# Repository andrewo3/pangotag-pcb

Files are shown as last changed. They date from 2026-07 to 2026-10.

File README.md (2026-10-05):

# Pangotag PCB

KiCad 10 project for a GNSS and motion tracking tag for the white-bellied pangolin, built in the
Harvard Microrobotics Laboratory.

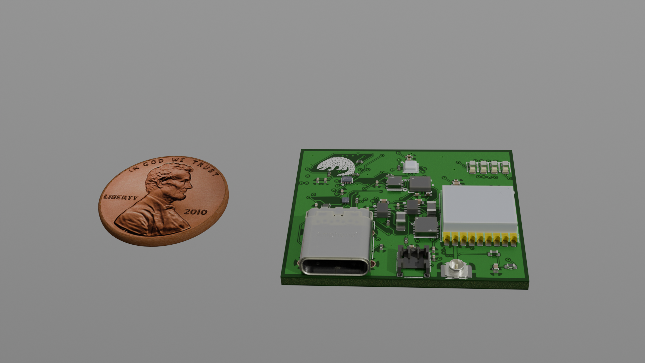
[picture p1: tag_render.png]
The V2 board next to a penny


## V2

`Pangotag_PCB_LCSC_compat4.kicad_pcb` is the V2 tag: a 31.94 × 27.18 mm, 6-layer, 1.6 mm board with
80 parts on both sides, using parts that JLCPCB stocks.

- STM32U575 microcontroller (LQFP-64) and a 32 GB eMMC on the underside
- u-blox MAX-M10S GNSS module with a U.FL antenna connector
- BMI270 IMU, BMP581 pressure sensor, T117 temperature sensor and LTC2944 coulomb counter on one I2C bus
- Two TPS62840 buck converters for always-on 1.9 V and 3.3 V rails, fed from a 2-pin battery connector
- USB-C for USB and, with a Type-C debug accessory, SWD: two comparators on CC1 and CC2 and an AND
  gate switch a TMUX1511 that puts SWCLK, SWDIO, SWO and NRST on contacts USB 2.0 leaves unused

`Dongle.kicad_pcb` is a 4-layer adapter that connects an ST-Link to the tag's USB-C port in either
orientation, with a reset button.

## Files

| Path | Contents |
| --- | --- |
| `Pangotag_PCB.kicad_sch` and its `Power`, `Communication`, `LEDs` and `st-link_conn` sheets | Schematic |
| `Pangotag_PCB_LCSC_compat4.kicad_pcb` | V2 tag board |
| `Dongle.kicad_pcb` | ST-Link debug dongle |
| `Pangotag_PCB.kicad_pcb` | The tag and an earlier dongle on one sheet |
| `Pangotag_PCB_LCSC_compat*.kicad_pcb`, `Only_Tag*.kicad_pcb` | Intermediate revisions |
| `jlcpcb/` | JLCPCB Gerber, BOM and placement files |
| `export_footprints.pretty/`, `FBGA153.pretty/`, `*.kicad_sym` | Project footprint and symbol libraries |
| `tag_render*.png` | Renders of the board and an enclosure model |

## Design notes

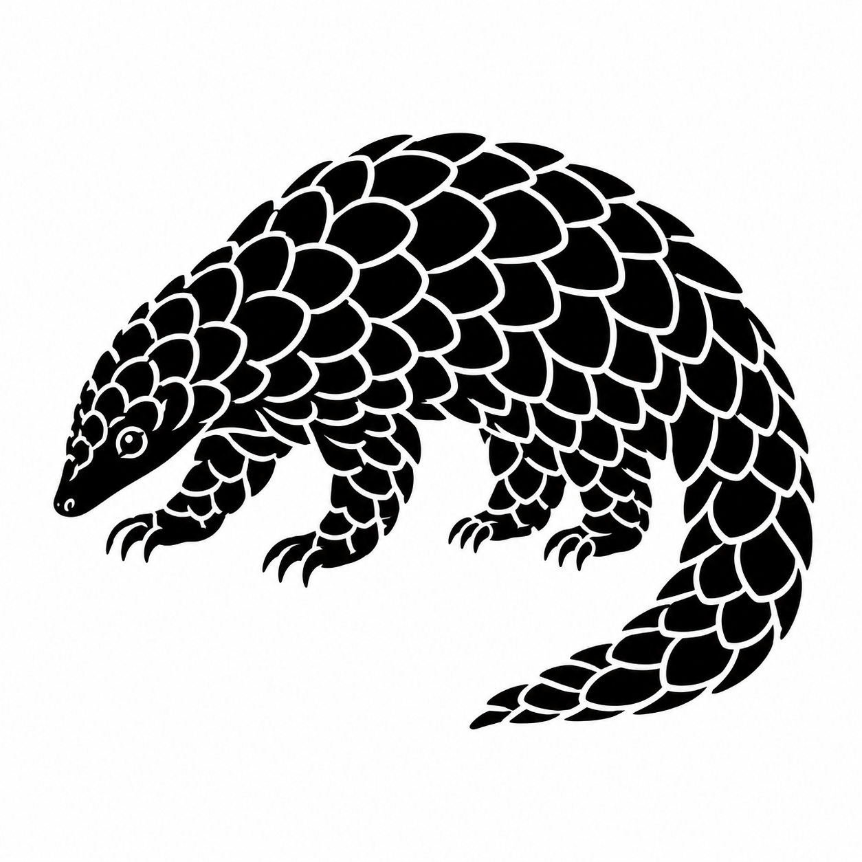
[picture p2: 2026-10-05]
pangolin_decal.png

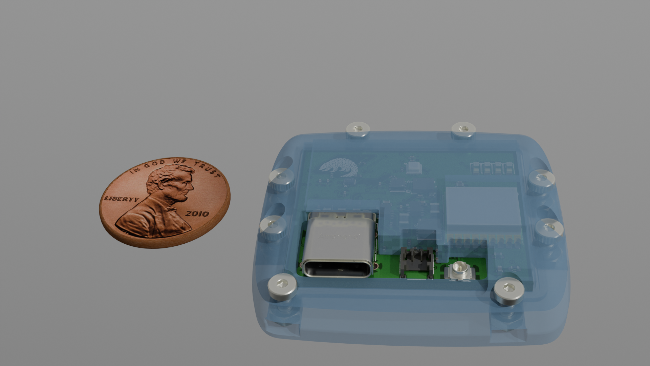
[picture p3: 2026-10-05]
tag_render2.png

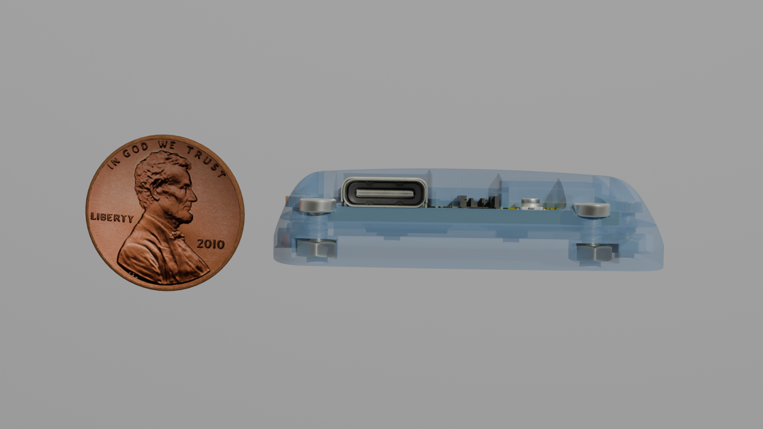
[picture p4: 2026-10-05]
tag_render3.png

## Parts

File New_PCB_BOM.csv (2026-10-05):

Id | Designator | Footprint | Quantity | Designation | Supplier and ref
1 | BT1, BT2, BT3 | BAT_2996 | 3 | 2996
2 | C1, C2, C3, C10, C15, C18, C20, C21, C23, C29, C36, C37, C39, C40 | C_0201_0603Metric | 14 | 100n
3 | C7, C8, C11 | C_0201_0603Metric | 3 | 4.7u
4 | C13 | C_0201_0603Metric | 1 | 0.1u
5 | C16, C17 | C_0201_0603Metric | 2 | 8p
6 | C19, C22, C24, C25, C30, C35 | C_0201_0603Metric | 6 | 10u
7 | C38 | C_0201_0603Metric | 1 | 1u
8 | C41, C42 | C_0201_0603Metric | 2 | 2.2u
9 | CN2 | PinSocket_2x03_P2.54mm_Vertical_SMD | 1 | POGOPIN_2X04_P2.54_M
10 | D1 | LED_0201_0603Metric | 1 | XZCM2CRK53WA-1VF
11 | D2 | LED_0201_0603Metric | 1 | XZCM2CYK53WA-1VF
12 | D3 | LED_0201_0603Metric | 1 | XZCDGK53W-1VF
13 | D4 | LED_0201_0603Metric | 1 | XZCFBB53W-1VF
14 | IC1, IC2 | TLV3691IDPFR | 2 | TLV3691IDPFR
15 | IC3, IC4 | SON50P150X200X100-8N-D | 2 | TPS62840DLCR
16 | IC5, IC6 | TS3A5018RSVR | 2 | TS3A5018RSVR
17 | J1 | USB_C_Receptacle_Amphenol_12401610E4-2A_CircularHoles | 1 | USB_C_Receptacle
18 | J2 | U.FL_Hirose_U.FL-R-SMT-1_Vertical | 1 | Conn_Coaxial
19 | J3 | USB_Mini-B_Lumberg_2486_01_Horizontal | 1 | USB_B_Mini
20 | J4 | USB_A_Molex_48037-2200_Horizontal | 1 | USB_A
21 | J5 | Hirose_DF57H-2P-1.2V_1x02_P1.2mm_Socket | 1 | Conn_01x02
22 | L1 | L_0201_0603Metric | 1 | 100n
23 | L4, L5, L6, L7 | L_0201_0603Metric | 4 | 2.2u
24 | P1 | USB_C_Plug_ShenzhenJingTuoJin_918-118A2021Y40002_Vertical | 1 | USB_C_Plug
25 | Q1, Q2, Q3, Q4 | PMX100UNZ | 4 | PMX100UNZ
26 | R1, R2, R12 | R_0201_0603Metric | 3 | 10k
27 | R3, R4 | R_0201_0603Metric | 2 | 5.1k
28 | R5, R14 | R_0201_0603Metric | 2 | 56k
29 | R6 | R_0201_0603Metric | 1 | 900
30 | R7 | R_0201_0603Metric | 1 | 725
31 | R8, R9 | R_0201_0603Metric | 2 | 325
32 | R13 | R_0201_0603Metric | 1 | 267k
33 | R15 | R_0201_0603Metric | 1 | 1M
34 | R16 | R_0201_0603Metric | 1 | 500k
35 | R21 | R_0201_0603Metric | 1 | 80M
36 | R22 | R_0201_0603Metric | 1 | 10M
37 | SW1 | SW_SPST_B3U-1000P | 1 | SW_Push
38 | U2 | BGA153N50P14X14_1150X1300X80 | 1 | ~
39 | U3 | DPW0005A_TEX | 1 | SN74AUP1G08DPWR
40 | U4 | ublox_MAX | 1 | MAX-M10S
41 | U7 | DFN-6-1EP_3x2mm_P0.5mm_EP1.65x1.35mm | 1 | LTC2941IDCB-1#TRMPBF
42 | U8 | LQFP-64_10x10mm_P0.5mm | 1 | STM32U585RITxQ
43 | U11 | BGA6C40P2X3_102X150X52 | 1 | AS6221T-AWLT
44 | U14 | BMP581 | 1 | BMP581
45 | U16 | BMI270_BOS | 1 | BMI270
46 | U18 | BGA6N40P3X2_146X96X50N | 1 | TPS62840YBGR
47 | Y1 | XTAL_CM9V-T1A-32.768KHZ-7PF-20PPM-TA-QC | 1 | CM9V-T1A-32.768KHZ-7PF-20PPM-TA-QC

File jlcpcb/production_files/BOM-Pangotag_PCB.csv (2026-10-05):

Comment | Designator | Footprint | LCSC | Quantity
0.1u | C13 | C_0201_0603Metric | C66938 | 1
10 | R5 | R_0402_1005Metric | C25077 | 1
100n | C1,C10,C15,C18,C2,C20,C21,C23,C26,C27,C28,C29,C3,C31,C32,C36,C37,C39,C40 | C_0201_0603Metric | C66938 | 19
10M | R22 | R_0201_0603Metric | C470889 | 1
10k | R1,R12,R2 | R_0201_0603Metric | C98098 | 3
10n | C4 | C_0402_1005Metric | C1524 | 1
10u | C19,C22,C24,C25,C30,C35 | C_0402_1005Metric | C15525 | 6
1M | R15 | R_0201_0603Metric | C102686 | 1
1u | C38 | C_0201_0603Metric | C53067 | 1
2.2u | C41,C42 | C_0201_0603Metric | C77762 | 2
2.2u | L4,L5,L6,L7 | L_0805_2012Metric | C98033 | 4
267k | R13 | R_0201_0603Metric | C423627 | 1
27n | L1 | L_0402_1005Metric | C12669 | 1
325 | R8,R9 | R_0201_0603Metric | C100175 | 2
4.7u | C11,C7,C8 | C_0201_0603Metric | C335103 | 3
5.1k | R3,R4 | R_0201_0603Metric | C163490 | 2
500k | R16 | R_0201_0603Metric | C158436 | 1
56k | R10,R17 | R_0201_0603Metric | C473524 | 2
725 | R7 | R_0201_0603Metric | C138124 | 1
80M | R21 | R_0201_0603Metric | C423539 | 1
8p | C16,C17 | C_0201_0603Metric | C85917 | 2
900 | R6 | R_0201_0603Metric | C158303 | 1
BMI270 | U16 | BMI270_BOS | C2836813 | 1
BMP581 | U14 | BMP581 | C5362283 | 1
CM9V-T1A-32.768KHZ-7PF-20PPM-TA-QC | Y1 | XTAL_CM9V-T1A-32.768KHZ-7PF-20PPM-TA-QC | C5341288 | 1
Conn_01x02 | J5 | Hirose_DF57H-2P-1.2V_1x02_P1.2mm_Socket | C202104 | 1
Conn_Coaxial | J2 | U.FL_Hirose_U.FL-R-SMT-1_Vertical | C88373 | 1
MAX-M10S | U4 | ublox_MAX | C4153167 | 1
PMX100UNZ | Q1,Q2,Q3,Q4 | PMX100UNZ | C20235855 | 4
POGOPIN_2X04_P2.54_M | CN2 | PinHeader_2x03_P2.54mm_Vertical | C5116527 | 1
SN74AUP1G08DPWR | U3 | DPW0005A_TEX | C2872914 | 1
STM32U585RITxQ | U8 | LQFP-64_10x10mm_P0.5mm | C5271044 | 1
SW_Push | SW1 | SW_SPST_B3U-1000P | C128937 | 1
TLV3691IDPFR | IC1,IC2 | TLV3691IDPFR | C140305 | 2
TPS62840DLCR | IC3,IC4 | SON50P150X200X100-8N-D | C2071859 | 2
TPS62840YBGR | U18 | BGA6N40P3X2_146X96X50N | C2071139 | 1
UP32-C-F-G-FL-3-P24-TR | J4 | USB-TH-TYPE-C_00702-UCAM002-X | C3148227 | 1
USB_B_Mini | J3 | USB_Mini-B_Lumberg_2486_01_Horizontal | C46391 | 1
USB_C_Receptacle | J1 | USB_C_Receptacle_Amphenol_12401610E4-2A_CircularHoles | C464604 | 1
XZCDGK53W-1VF | D3 | LED_0603_1608Metric | C598356 | 1
XZCFBB53W-1VF | D4 | LED_0603_1608Metric | C5200747 | 1
XZCM2CRK53WA-1VF | D1 | LED_0603_1608Metric | C241893 | 1
XZCM2CYK53WA-1VF | D2 | LED_0603_1608Metric | C2900143 | 1
AS6221T-AWLT | U11 | BGA6C40P2X3_102X150X52 |  | 1
LTC2941IDCB-1#TRMPBF | U7 | DFN-6-1EP_3x2mm_P0.5mm_EP1.65x1.35mm |  | 1
NSEC3T016-IT | U2 | BGA153N50P14X14_1150X1300X80 |  | 1

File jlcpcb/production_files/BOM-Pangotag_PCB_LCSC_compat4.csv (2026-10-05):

Comment | Designator | Footprint | LCSC | Quantity
0.1u | C13 | C_0201_0603Metric | C66938 | 1
10 | R5 | R_0402_1005Metric | C25077 | 1
100n | C1,C10,C14,C15,C18,C2,C20,C21,C23,C26,C27,C28,C29,C3,C31,C36,C37,C39,C40 | C_0201_0603Metric | C66938 | 19
100p | C30 | C_0201_0603Metric | C62550 | 1
10M | R22 | R_0201_0603Metric | C470889 | 1
10k | R1,R19,R2,R20 | R_0201_0603Metric | C98098 | 4
10n | C4 | C_0402_1005Metric | C1524 | 1
10u | C22,C24,C25,C35 | C_0402_1005Metric | C15525 | 4
1M | R15 | R_0201_0603Metric | C102686 | 1
1u | C38 | C_0201_0603Metric | C53067 | 1
2.2u | L5,L7 | L_0805_2012Metric | C98033 | 2
200k | R18 | R_0201_0603Metric | C138163 | 1
267k | R13 | R_0201_0603Metric | C423627 | 1
27n | L1 | L_0402_1005Metric | C12669 | 1
325 | R8,R9 | R_0201_0603Metric | C100175 | 2
4.7u | C33,C7,C8 | C_0201_0603Metric | C335103 | 3
5.1k | R3,R4 | R_0201_0603Metric | C163490 | 2
500k | R16 | R_0201_0603Metric | C158436 | 1
50m | R23 | R_0201_0603Metric | C42144 | 1
725 | R7 | R_0201_0603Metric | C138124 | 1
74AUP1G08GS_132 | U1 | XSON6_SOT1202_NEX | C554940 | 1
80M | R21 | R_0201_0603Metric | C423539 | 1
8p | C16,C17 | C_0201_0603Metric | C85917 | 2
900 | R6 | R_0201_0603Metric | C158303 | 1
909 | R14 | R_0201_0603Metric | C474301 | 1
BMI270 | U16 | BMI270_BOS | C2836813 | 1
BMP581 | U14 | BMP581 | C5362283 | 1
CM9V-T1A-32.768KHZ-7PF-20PPM-TA-QC | Y1 | XTAL_CM9V-T1A-32.768KHZ-7PF-20PPM-TA-QC | C5341288 | 1
Conn_01x02 | J5 | Hirose_DF57H-2P-1.2V_1x02_P1.2mm_Socket | C202104 | 1
Conn_Coaxial | J2 | U.FL_Hirose_U.FL-R-SMT-1_Vertical | C88373 | 1
LTC2944IDD#PBF | U6 | DFN-8_L3.0-W3.0-P0.50-BL-EP | C683669 | 1
MAX-M10S | U4 | ublox_MAX | C4153167 | 1
PCA9306DQER | U8 | X2SON-8_L1.4-W1.0-P0.35-BL | C440032 | 1
PMX100UNZ | Q1,Q2,Q3,Q4 | PMX100UNZ | C20235855 | 4
STM32U575RGTx | U5 | LQFP-64_10x10mm_P0.5mm | C5270980 | 1
T117_C19284874 | U3 | TDFN-6_L2.0-W2.0-P0.65-TL-EP | C19284874 | 1
TLV7031DPWR | U10,U9 | X2SON-4_L0.8-W0.8-P0.48-TL-A | C2876045 | 2
TMUX1511RSVR | U7 | UTQFN-16_L2.6-W1.8-P0.40-BL | C2673275 | 1
TPS62840DLCR | IC3,IC4 | SON50P150X200X100-8N-D | C2071859 | 2
USB_C_Receptacle | J1 | USB_C_Receptacle_Amphenol_12401610E4-2A_CircularHoles | C464604 | 1
XZCDGK53W-1VF | D3 | LED_0603_1608Metric | C5246833 | 1
XZCFBB53W-1VF | D4 | LED_0603_1608Metric | C5200747 | 1
XZCM2CRK53WA-1VF | D1 | LED_0603_1608Metric | C241893 | 1
XZCM2CYK53WA-1VF | D2 | LED_0603_1608Metric | C2900143 | 1
~ | U2 | BGA153N50P14X14_1150X1300X80 | C5821038 | 1

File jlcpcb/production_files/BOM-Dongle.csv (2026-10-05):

Comment | Designator | Footprint | LCSC | Quantity
10k | R12 | R_0402_1005Metric | C60489 | 1
10u | C19 | C_0402_1005Metric | C15525 | 1
2.2u | L4 | L_0805_2012Metric | C98033 | 1
4.7u | C11 | C_0402_1005Metric | C23733 | 1
56k | R10,R17 | R_0402_1005Metric | C25567 | 2
POGOPIN_2X04_P2.54_M | CN2 | PinHeader_2x03_P2.54mm_Vertical | C239343 | 1
SW_Push | SW1 | SW_SPST_B3U-1000P | C231329 | 1
TPS62840YBGR | U18 | BGA6N40P3X2_146X96X50N | C2071139 | 1
UP32-C-F-G-FL-3-P24-TR | J4 | USB-TH-TYPE-C_00702-UCAM002-X | C3148227 | 1
USB_B_Mini | J3 | USB_Mini-B_Lumberg_2486_01_Horizontal | C46391 | 1

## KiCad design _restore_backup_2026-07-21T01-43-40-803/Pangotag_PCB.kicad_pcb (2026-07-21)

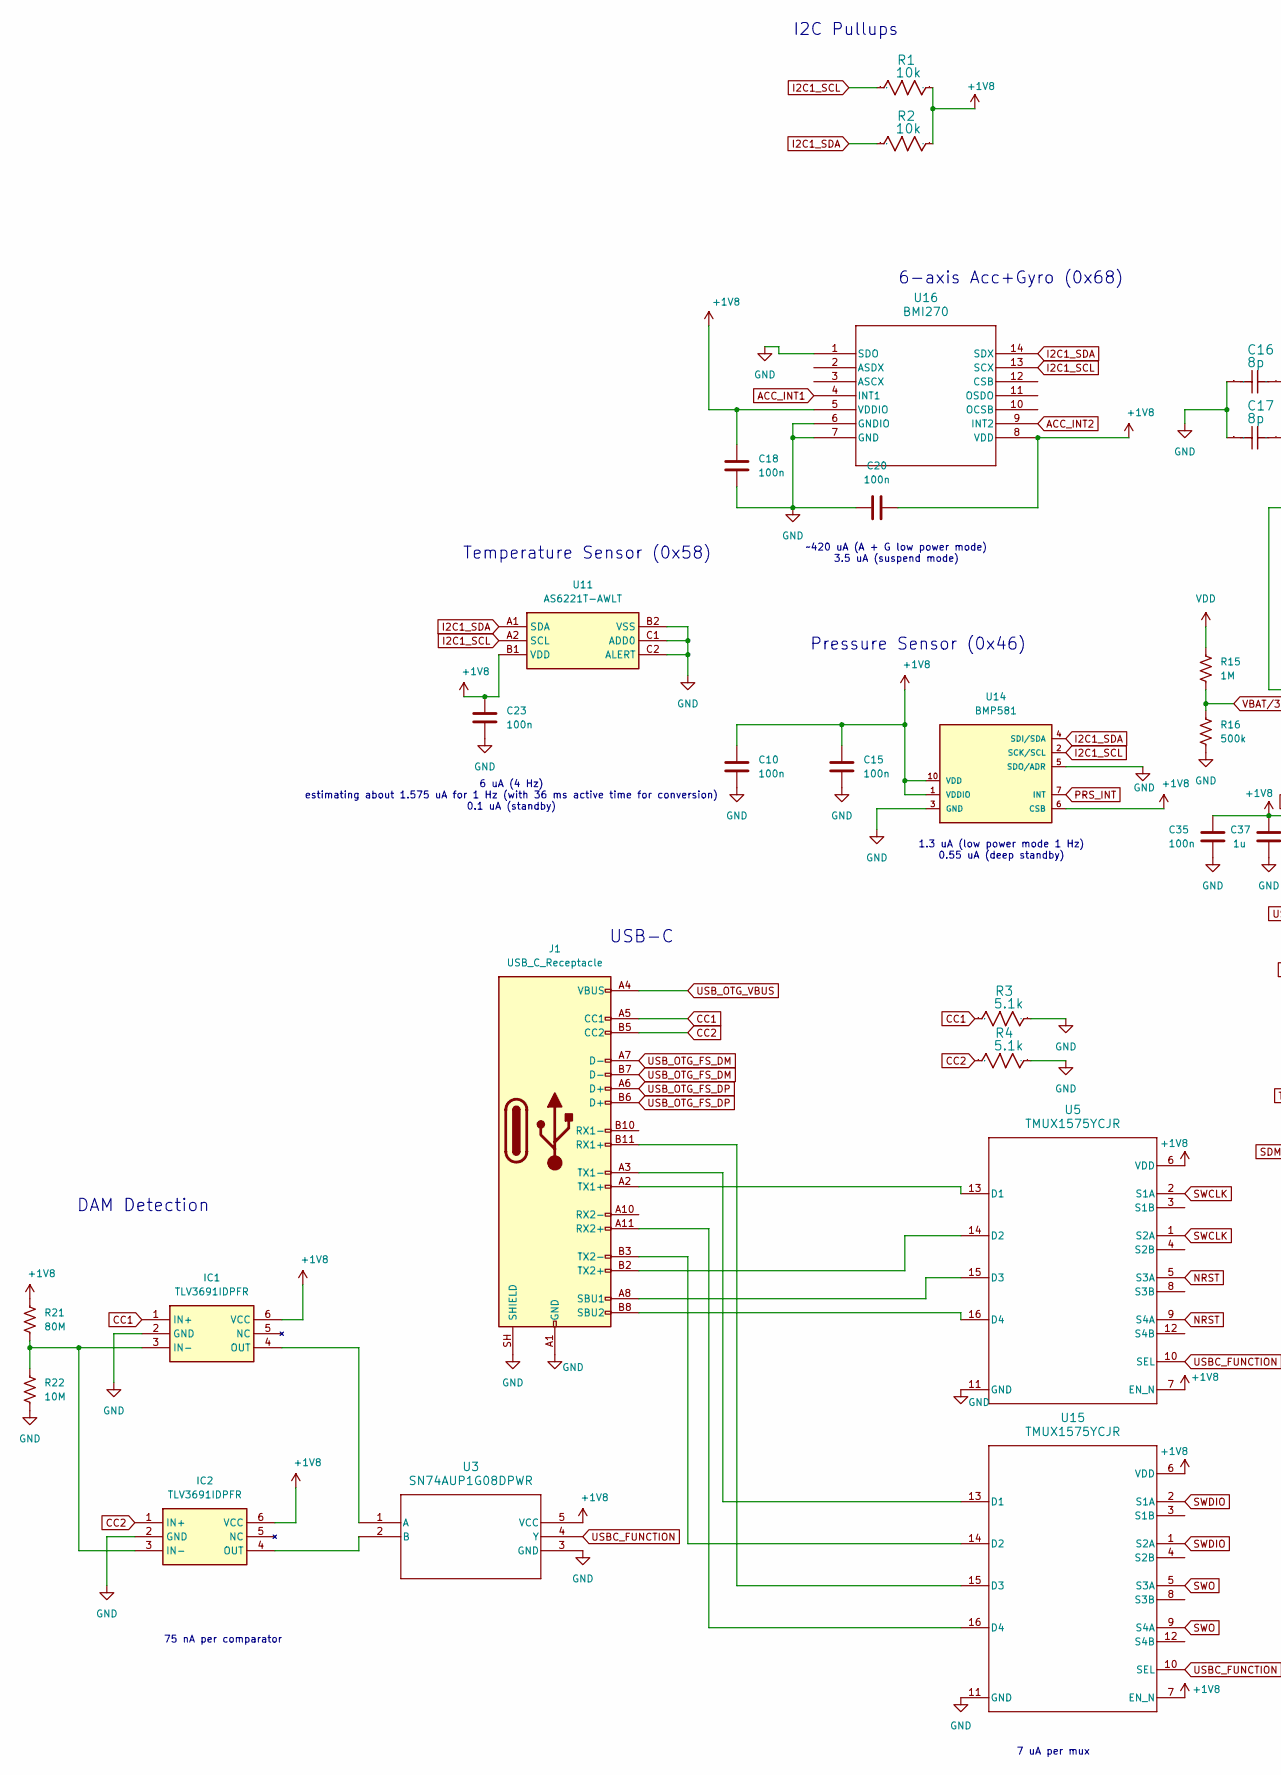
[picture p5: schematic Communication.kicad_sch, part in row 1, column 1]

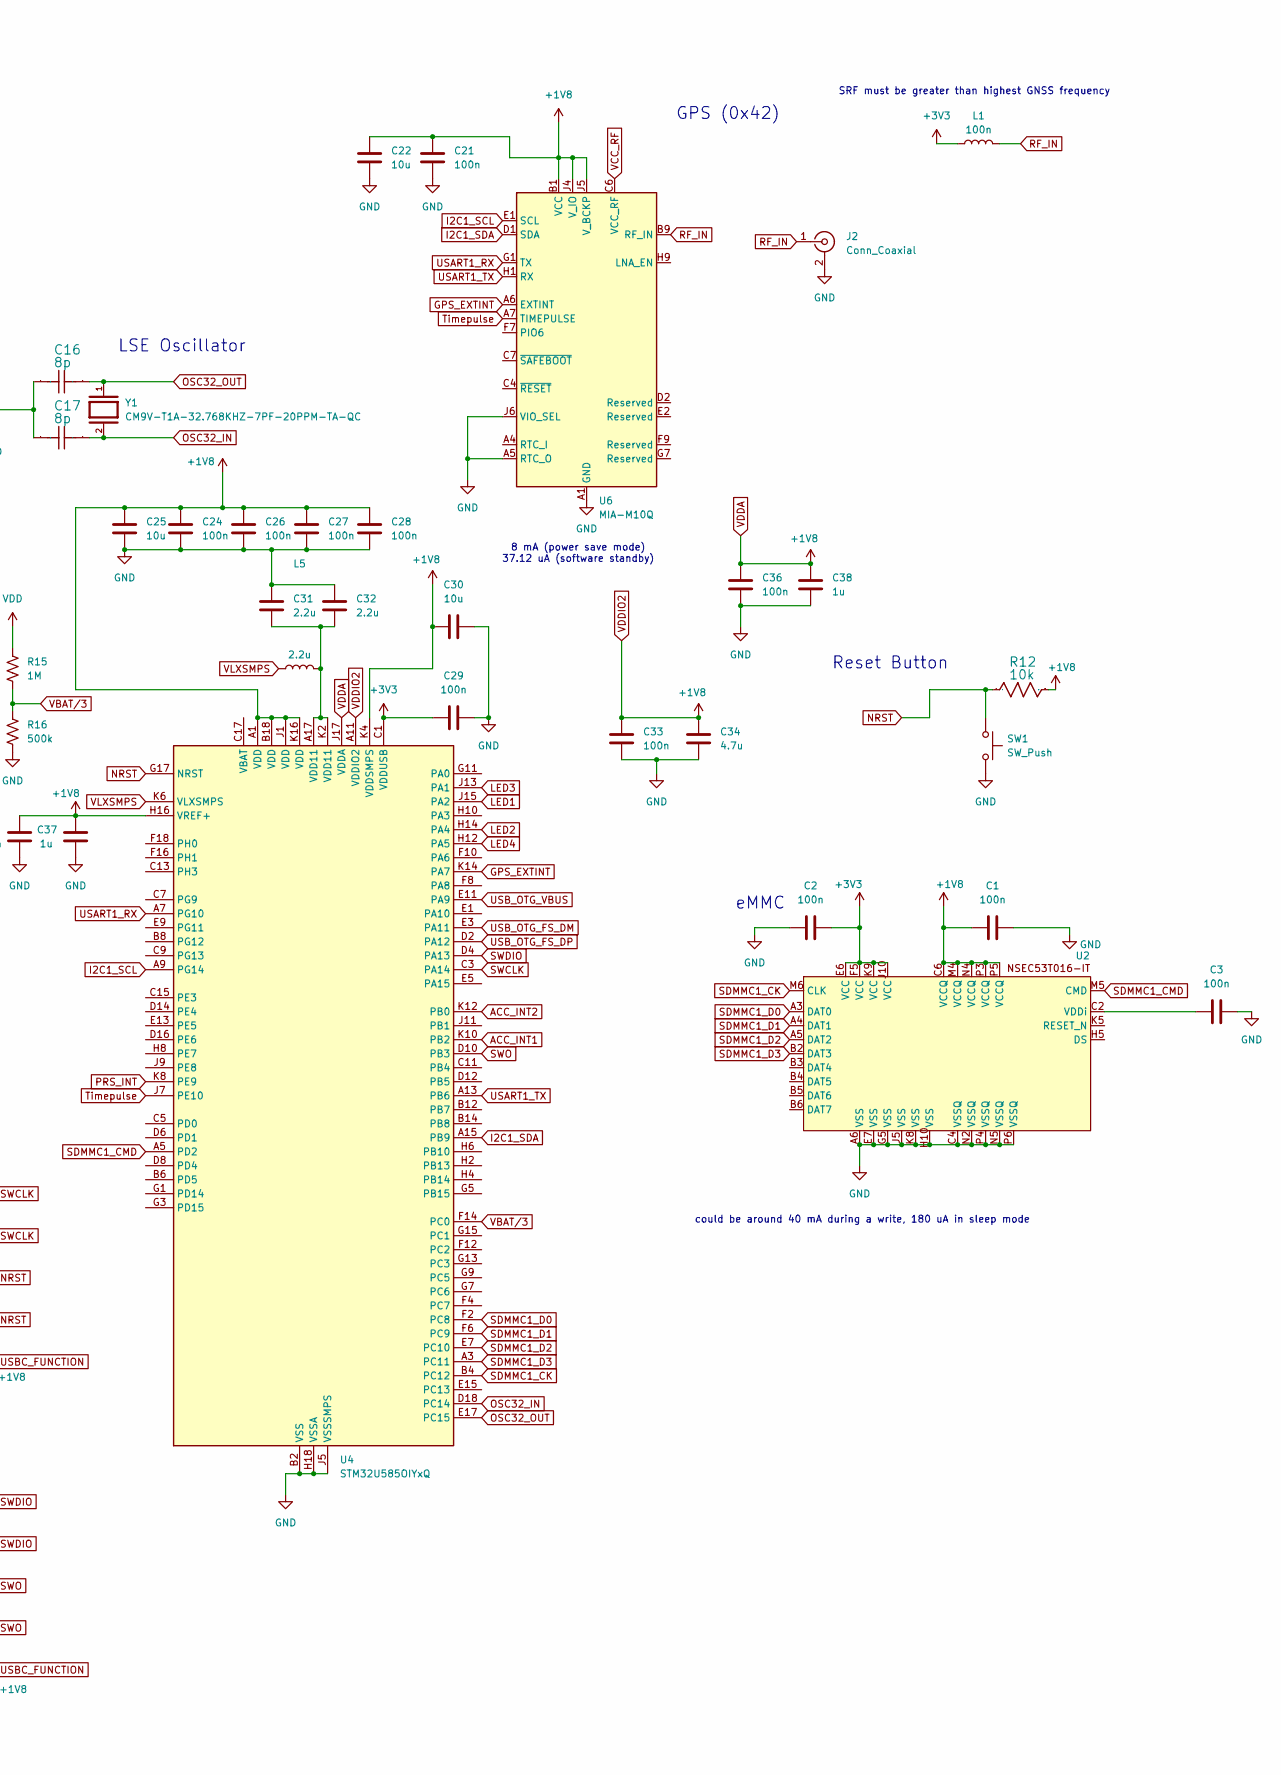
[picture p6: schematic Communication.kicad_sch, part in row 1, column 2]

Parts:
C1, C2, C3, C10, C15, C18, C20, C21, C23, C24, C26, C27, C28, C29, C33, C35, C36: 100n; C_0201_0603Metric
C16, C17: 8p; C_0201_0603Metric
C22, C25, C30: 10u; C_0201_0603Metric
C31, C32: 2.2u; C_0201_0603Metric
C34: 4.7u; C_0201_0603Metric
C37, C38: 1u; C_0201_0603Metric
IC1, IC2: TLV3691IDPFR; Manufacturer_Part_Number TLV3691IDPFR; Mouser Part Number 595-TLV3691IDPFR
J1: USB_C_Receptacle; USB_C_Receptacle_Amphenol_12401610E4-2A_CircularHoles
J2: Conn_Coaxial; U.FL_Hirose_U.FL-R-SMT-1_Vertical
L1: 100n; L_0201_0603Metric
L5: 2.2u; L_0201_0603Metric
R1, R2, R12: 10k; R_0201_0603Metric
R3, R4: 5.1k; R_0201_0603Metric
R15: 1M; R_0201_0603Metric
R16: 500k; R_0201_0603Metric
R21: 80M; R_0201_0603Metric
R22: 10M; R_0201_0603Metric
SW1: SW_Push; SW_SPST_B3U-1000P
U2: BGA153N50P14X14_1150X1300X80
U3: SN74AUP1G08DPWR; DPW0005A_TEX
U4: STM32U585OIYxQ; ST_WLCSP-90_4.2x3.95mm_Layout18x10_P0.4mm_Stagger
U5, U15: TMUX1575YCJR; PREYCJ0016-IPC_A
U6: MIA-M10Q; ublox_LGA-53_4.5x4.5mm_Layout9x9_P0.5mm
U11: AS6221T-AWLT; BGA6C40P2X3_102X150X52; Manufacturer_Part_Number AS6221T-AWLT; Mouser Part Number 985-AS6221T-AWLT
U14: BMP581
U16: BMI270; BMI270_BOS
Y1: CM9V-T1A-32.768KHZ-7PF-20PPM-TA-QC; XTAL_CM9V-T1A-32.768KHZ-7PF-20PPM-TA-QC; PARTREV 8.2/07.2022

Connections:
+3V3: C2.2, C29.2, L1.1, U2.E6 (VCC), U2.F5 (VCC), U2.J10 (VCC), U2.K9 (VCC), U4.C1 (VDDUSB); also elsewhere on the board
ACC_INT1: U4.K10 (PB2), U16.4 (INT1)
ACC_INT2: U4.K12 (PB0), U16.9 (INT2)
CC1: IC1.1 (IN+), J1.A5 (CC1), R3.1
CC2: IC2.1 (IN+), J1.B5 (CC2), R4.1
GND: C1.2, C2.1, C3.2, C10.2, C15.2, C16.1, C17.1, C18.2, C20.1, C21.2, C22.2, C23.2, C24.1, C25.1, C26.1, C27.1, C28.1, C29.1, C30.1, C31.2, C32.2, C33.1, C34.1, C35.1, C36.1, C37.1, C38.1, IC1.2 (GND), IC2.2 (GND), J1.A1 (GND), J1.A12 (GND), J1.B1 (GND), J1.B12 (GND), J1.SH (SHIELD), J2.2 (Ext), R3.2, R4.2, R16.2, R22.2, SW1.2, U2.A6 (VSS), U2.C4 (VSSQ), U2.E7 (VSS), U2.G5 (VSS), U2.H10 (VSS), U2.J5 (VSS), U2.K8 (VSS), U2.N2 (VSSQ), U2.N5 (VSSQ), U2.P4 (VSSQ), U2.P6 (VSSQ), U3.3 (GND), U4.B2 (VSS), U4.B10 (VSS), U4.B16 (VSS), U4.H18 (VSSA), U4.J3 (VSS), U4.J5 (VSSSMPS), U4.K18 (VSS), U5.11 (GND), U6.A1 (GND), U6.A2 (GND), U6.A3 (GND), U6.A5 (RTC_O), U6.A8 (GND), U6.A9 (GND), U6.B2 (GND), U6.B8 (GND), U6.C3 (GND), U6.C9 (GND), U6.E3 (GND), U6.E4 (GND), U6.E9 (GND), U6.F1 (GND), U6.F3 (GND), U6.F4 (GND), U6.G3 (GND), U6.G4 (GND), U6.G5 (GND), U6.G6 (GND), U6.H8 (GND), U6.J6 (VIO_SEL), U6.J8 (GND), U6.J9 (GND), U11.B2 (VSS), U11.C1 (ADD0), U11.C2 (ALERT), U14.3 (GND), U14.5 (SDO/ADR), U14.8 (GND), U14.9 (GND), U15.11 (GND), U16.1 (SDO), U16.6 (GNDIO), U16.7 (GND); also elsewhere on the board
GPS_EXTINT: U4.K14 (PA7), U6.A6 (EXTINT)
I2C1_SCL: R1.1, U4.A9 (PG14), U6.E1 (SCL), U11.A2 (SCL), U14.2 (SCK/SCL), U16.13 (SCX); also elsewhere on the board
I2C1_SDA: R2.1, U4.A15 (PB9), U6.D1 (SDA), U11.A1 (SDA), U14.4 (SDI/SDA), U16.14 (SDX); also elsewhere on the board
LED1: U4.J15 (PA2); also elsewhere on the board
LED2: U4.H14 (PA4); also elsewhere on the board
LED3: U4.J13 (PA1); also elsewhere on the board
LED4: U4.H12 (PA5); also elsewhere on the board
NRST: R12.2, SW1.1, U4.G17 (NRST), U5.5 (S3A), U5.9 (S4A)
unnamed: C31.1, C32.1, L5.2, U4.A17 (VDD11), U4.K2 (VDD11)
unnamed: IC1.3 (IN-), IC2.3 (IN-), R21.2, R22.1
unnamed: IC1.4 (OUT), U3.1 (A)
unnamed: IC2.4 (OUT), U3.2 (B)
unnamed: J1.B11 (RX1+), U15.15 (D3)
unnamed: J1.A11 (RX2+), U15.16 (D4)
unnamed: J1.A8 (SBU1), U5.15 (D3)
unnamed: J1.B8 (SBU2), U5.16 (D4)
unnamed: J1.A2 (TX1+), U5.13 (D1)
unnamed: J1.A3 (TX1-), U15.13 (D1)
unnamed: J1.B2 (TX2+), U5.14 (D2)
unnamed: J1.B3 (TX2-), U15.14 (D2)
unnamed: C3.1, U2.C2 (VDDi)
OSC32_IN: C17.2, U4.D18 (PC14), Y1.2
OSC32_OUT: C16.2, U4.E17 (PC15), Y1.1
PRS_INT: U4.K8 (PE9), U14.7 (INT)
RF_IN: J2.1 (In), L1.2, U6.B9 (RF_IN)
SDMMC1_CK: U2.M6 (CLK), U4.B4 (PC12)
SDMMC1_CMD: U2.M5 (CMD), U4.A5 (PD2)
SDMMC1_D0: U2.A3 (DAT0), U4.F2 (PC8)
SDMMC1_D1: U2.A4 (DAT1), U4.F6 (PC9)
SDMMC1_D2: U2.A5 (DAT2), U4.E7 (PC10)
SDMMC1_D3: U2.B2 (DAT3), U4.A3 (PC11)
SWCLK: U4.C3 (PA14), U5.1 (S2A), U5.2 (S1A)
SWDIO: U4.D4 (PA13), U15.1 (S2A), U15.2 (S1A)
SWO: U4.D10 (PB3), U15.5 (S3A), U15.9 (S4A)
Timepulse: U4.J7 (PE10), U6.A7 (TIMEPULSE)
USART1_RX: U4.A7 (PG10), U6.G1 (TX)
USART1_TX: U4.A13 (PB6), U6.H1 (RX)
USBC_FUNCTION: U3.4 (Y), U5.10 (SEL), U15.10 (SEL)
USB_OTG_FS_DM: J1.A7 (D-), J1.B7 (D-), U4.E3 (PA11)
USB_OTG_FS_DP: J1.A6 (D+), J1.B6 (D+), U4.D2 (PA12)
USB_OTG_VBUS: J1.A4 (VBUS), J1.A9 (VBUS), J1.B4 (VBUS), J1.B9 (VBUS), U4.E11 (PA9)
VBAT/3: R15.2, R16.1, U4.F14 (PC0)
VCC_RF: U6.C6 (VCC_RF)
VDD: R15.1; also elsewhere on the board
VDDA: C1.1, C10.1, C15.1, C18.1, C20.2, C21.1, C22.1, C23.1, C24.2, C25.2, C26.2, C27.2, C28.2, C30.2, C33.2, C34.2, C35.2, C36.2, C37.2, C38.2, IC1.6 (VCC), IC2.6 (VCC), R1.2, R2.2, R12.1, R21.1, U2.C6 (VCCQ), U2.M4 (VCCQ), U2.N4 (VCCQ), U2.P3 (VCCQ), U2.P5 (VCCQ), U3.5 (VCC), U4.A1 (VDD), U4.A11 (VDDIO2), U4.B18 (VDD), U4.H16 (VREF+), U4.J1 (VDD), U4.J17 (VDDA), U4.K4 (VDDSMPS), U4.K16 (VDD), U5.6 (VDD), U5.7 (EN_N), U6.B1 (VCC), U6.J4 (V_IO), U6.J5 (V_BCKP), U11.B1 (VDD), U14.1 (VDDIO), U14.6 (CSB), U14.10 (VDD), U15.6 (VDD), U15.7 (EN_N), U16.5 (VDDIO), U16.8 (VDD); also elsewhere on the board
VLXSMPS: L5.1, U4.K6 (VLXSMPS)

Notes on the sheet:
Temperature Sensor (0x58)
GPS (0x42)
75 nA per comparator
I2C Pullups
SRF must be greater than highest GNSS frequency
Reset Button
8 mA (power save mode) 37.12 uA (software standby)
could be around 40 mA during a write, 180 uA in sleep mode
6-axis Acc+Gyro (0x68)
DAM Detection
eMMC
6 uA (4 Hz) estimating about 1.575 uA for 1 Hz (with 36 ms active time for conversion) 0.1 uA (standby)
7 uA per mux
1.3 uA (low power mode 1 Hz) 0.55 uA (deep standby)
LSE Oscillator
Pressure Sensor (0x46)
~420 uA (A + G low power mode) 3.5 uA (suspend mode)
USB-C

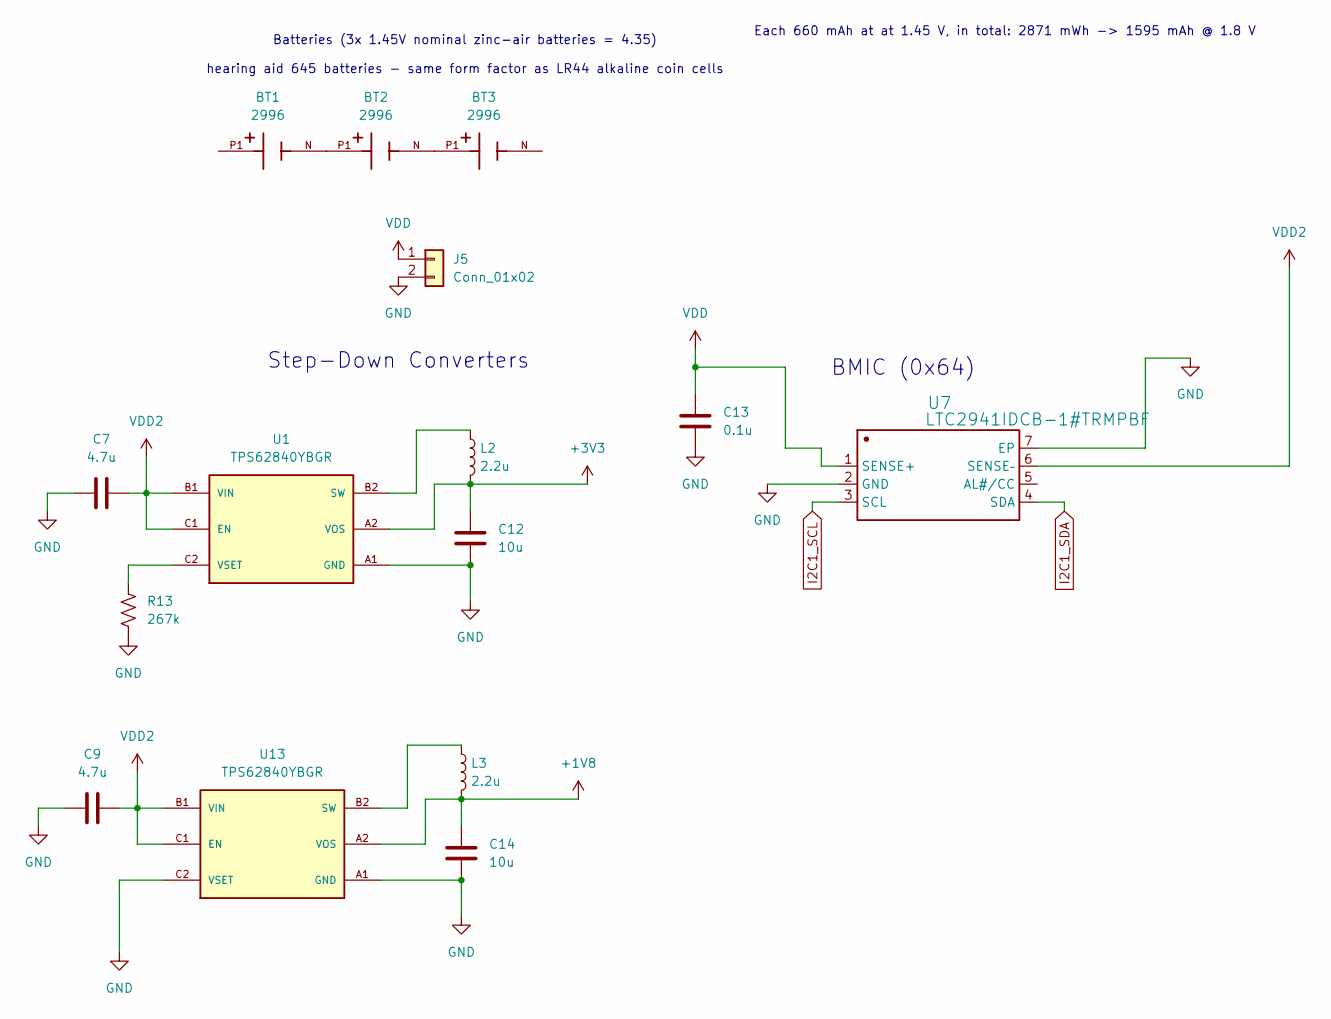
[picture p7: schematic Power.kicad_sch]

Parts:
BT1, BT2, BT3: 2996; BAT_2996; PARTREV F
C7, C9: 4.7u; C_0201_0603Metric
C12, C14: 10u; C_0201_0603Metric
C13: 0.1u; C_0201_0603Metric
J5: Conn_01x02; Hirose_DF57H-2P-1.2V_1x02_P1.2mm_Socket
L2, L3: 2.2u; L_0201_0603Metric
R13: 267k; R_0201_0603Metric
U1, U13: TPS62840YBGR; BGA6N40P3X2_146X96X50N; PARTREV D
U7: LTC2941IDCB-1#TRMPBF; DFN-6-1EP_3x2mm_P0.5mm_EP1.65x1.35mm; Manufacturer Part LTC2941IDCB-1#TRMPBF

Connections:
+3V3: C12.1, L2.2, U1.A2 (VOS); also elsewhere on the board
GND: C7.2, C9.2, C12.2, C13.2, C14.2, J5.2, R13.2, U1.A1 (GND), U7.2 (GND), U7.7 (EP), U13.A1 (GND), U13.C2 (VSET); also elsewhere on the board
I2C1_SCL: U7.3 (SCL); also elsewhere on the board
I2C1_SDA: U7.4 (SDA); also elsewhere on the board
unnamed: BT1.N, BT2.P1, BT2.P2
unnamed: BT1.P1, BT1.P2
unnamed: BT2.N, BT3.P1, BT3.P2
unnamed: L2.1, U1.B2 (SW)
unnamed: R13.1, U1.C2 (VSET)
unnamed: L3.1, U13.B2 (SW)
VDD: C13.1, J5.1, U7.1 (SENSE+); also elsewhere on the board
VDD2: C7.1, C9.1, U1.B1 (VIN), U1.C1 (EN), U7.6 (SENSE–), U13.B1 (VIN), U13.C1 (EN)
VDDA: C14.1, L3.2, U13.A2 (VOS); also elsewhere on the board

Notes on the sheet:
Each 660 mAh at at 1.45 V, in total: 2871 mWh -> 1595 mAh @ 1.8 V
BMIC (0x64)
Batteries (3x 1.45V nominal zinc-air batteries = 4.35) hearing aid 645 batteries - same form factor as LR44 alkaline coin cells
Step-Down Converters

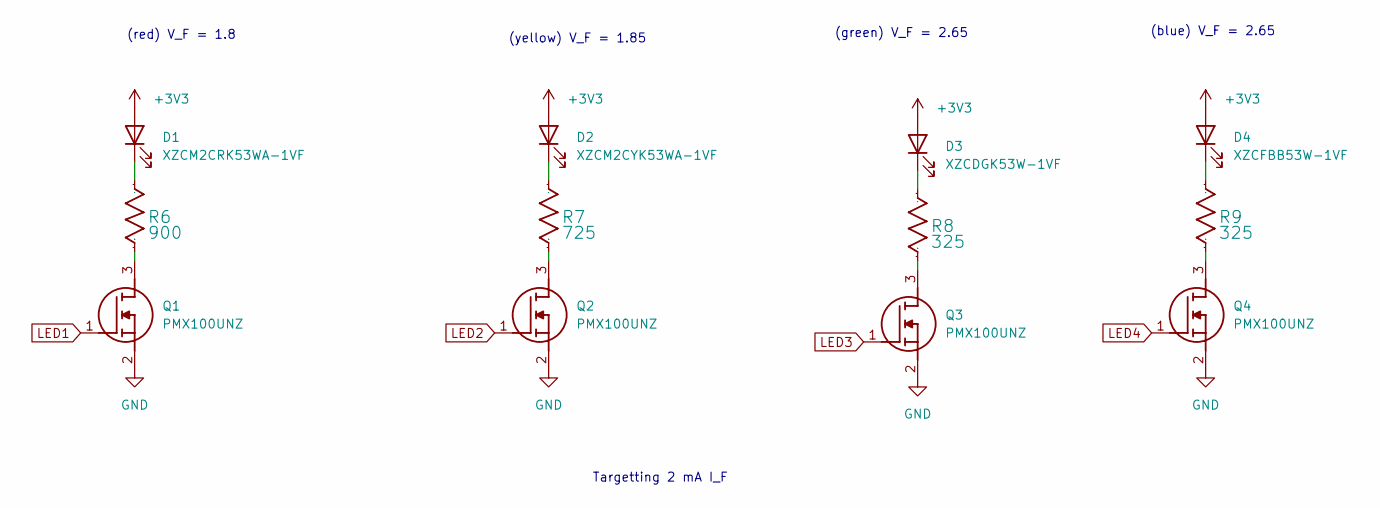
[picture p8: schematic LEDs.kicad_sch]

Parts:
D1: XZCM2CRK53WA-1VF; LED_0201_0603Metric
D2: XZCM2CYK53WA-1VF; LED_0201_0603Metric
D3: XZCDGK53W-1VF; LED_0201_0603Metric
D4: XZCFBB53W-1VF; LED_0201_0603Metric
Q1, Q2, Q3, Q4: PMX100UNZ; Manufacturer_Part_Number PMX100UNZ; Mouser Part Number 771-PMX100UNZ
R6: 900; R_0201_0603Metric
R7: 725; R_0201_0603Metric
R8, R9: 325; R_0201_0603Metric

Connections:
+3V3: D1.2 (A), D2.2 (A), D3.2 (A), D4.2 (A); also elsewhere on the board
GND: Q1.2 (S), Q2.2 (S), Q3.2 (S), Q4.2 (S); also elsewhere on the board
LED1: Q1.1 (G); also elsewhere on the board
LED2: Q2.1 (G); also elsewhere on the board
LED3: Q3.1 (G); also elsewhere on the board
LED4: Q4.1 (G); also elsewhere on the board
unnamed: D1.1 (K), R6.2
unnamed: D2.1 (K), R7.2
unnamed: D3.1 (K), R8.2
unnamed: D4.1 (K), R9.2
unnamed: Q1.3 (D), R6.1
unnamed: Q2.3 (D), R7.1
unnamed: Q3.3 (D), R8.1
unnamed: Q4.3 (D), R9.1

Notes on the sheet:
(blue) V_F = 2.65
(yellow) V_F = 1.85
(red) V_F = 1.8
(green) V_F = 2.65
Targetting 2 mA I_F

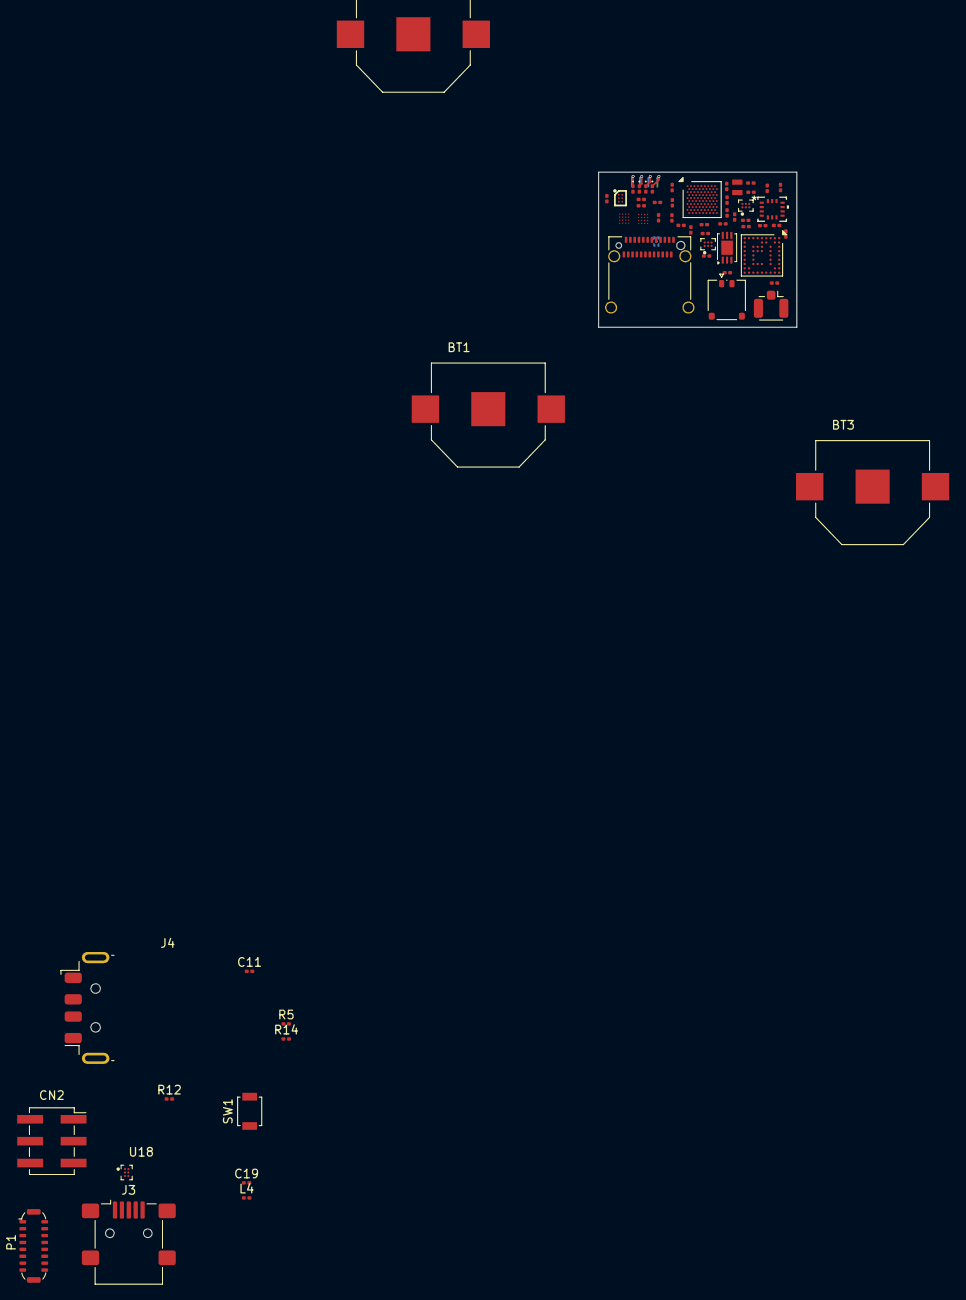
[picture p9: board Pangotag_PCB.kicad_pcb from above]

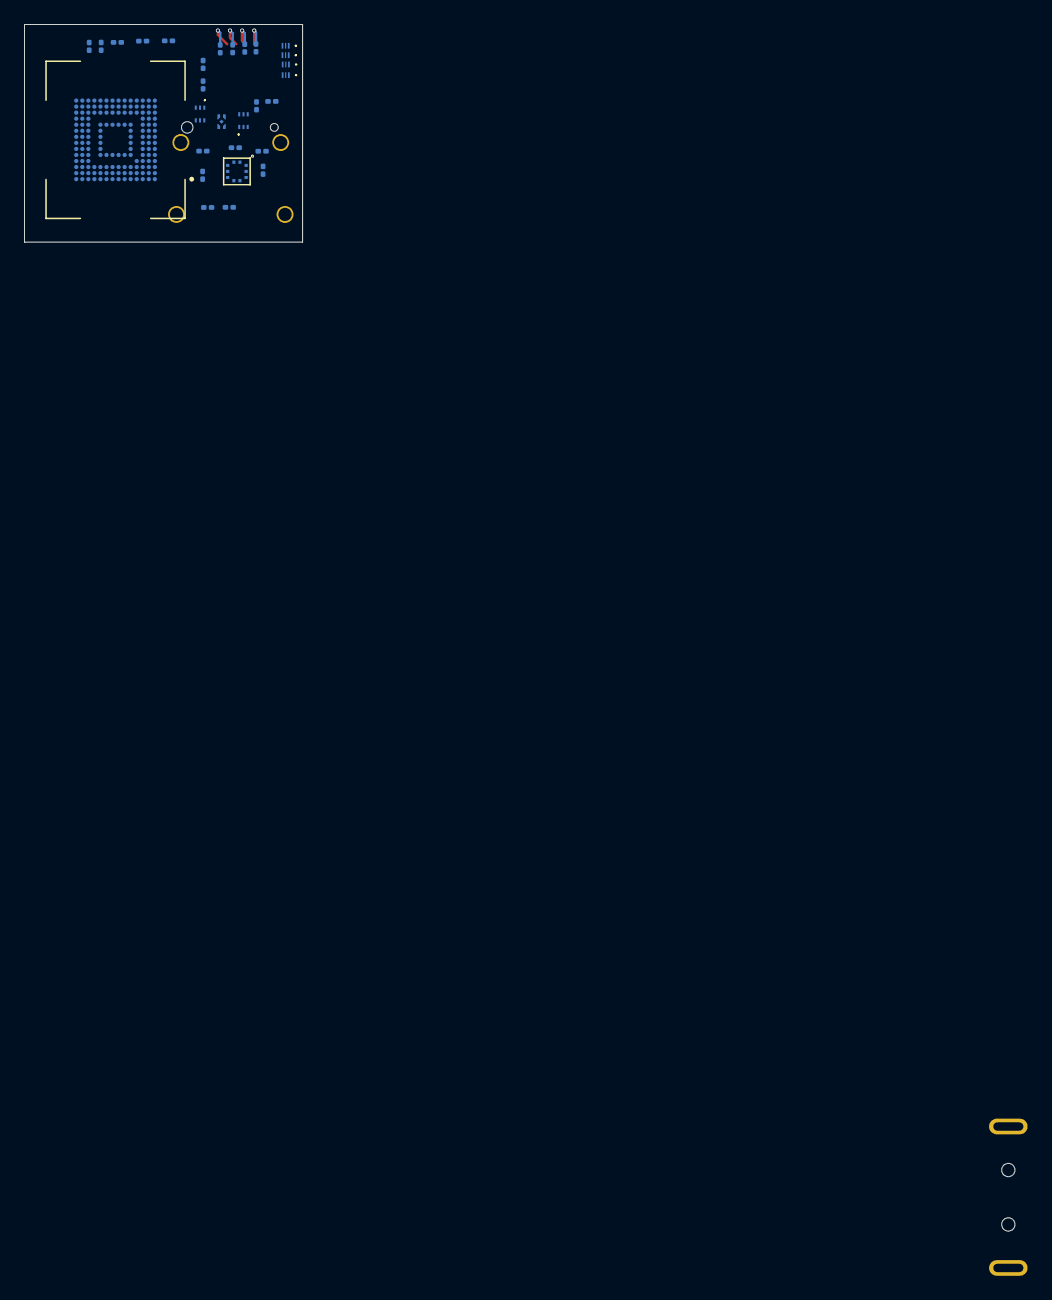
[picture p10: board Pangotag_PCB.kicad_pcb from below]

Board: 4 copper layers, 23.0 x 18.0 mm, 90 parts (29 on the bottom side), 74 nets.

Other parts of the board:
C11: 4.7u; C_0201_0603Metric
C19: 10u; C_0201_0603Metric
CN2: POGOPIN_2X04_P2.54_M; PinSocket_2x03_P2.54mm_Vertical_SMD
J3: USB_B_Mini; USB_Mini-B_Lumberg_2486_01_Horizontal
J4: USB_A; USB_A_Molex_48037-2200_Horizontal
L4: 2.2u; L_0201_0603Metric
P1: USB_C_Plug; USB_C_Plug_ShenzhenJingTuoJin_918-118A2021Y40002_Vertical
R5, R14: 56k; R_0201_0603Metric
U18: TPS62840YBGR; BGA6N40P3X2_146X96X50N

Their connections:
+1V8_2: C19.1, CN2.1, L4.2, U18.A2 (VOS)
GND: C11.2, C19.2, CN2.2, J3.5 (GND), J3.SH (Shield), J4.4 (GND), J4.SH (Shield), P1.A1 (GND), P1.A12 (GND), P1.B1 (GND), P1.B12 (GND), P1.SH (SHIELD), U18.A1 (GND), U18.C2 (VSET); also elsewhere on the board
NRST_OUT: CN2.6, P1.A8 (SBU1)
unnamed: J3.3 (D+), J4.3 (D+)
unnamed: J3.2 (D-), J4.2 (D-)
unnamed: P1.A5 (CC), R5.2
unnamed: P1.B5 (VCONN), R14.2
unnamed: L4.1, U18.B2 (SW)
VBUS_DONGLE: C11.1, J3.1 (VBUS), J4.1 (VBUS), P1.A4 (VBUS), P1.A9 (VBUS), P1.B4 (VBUS), P1.B9 (VBUS), R5.1, R14.1, U18.B1 (VIN), U18.C1 (EN)

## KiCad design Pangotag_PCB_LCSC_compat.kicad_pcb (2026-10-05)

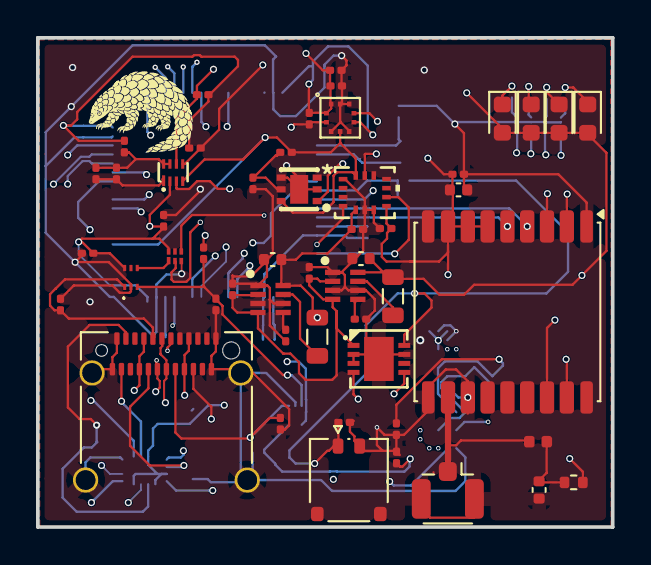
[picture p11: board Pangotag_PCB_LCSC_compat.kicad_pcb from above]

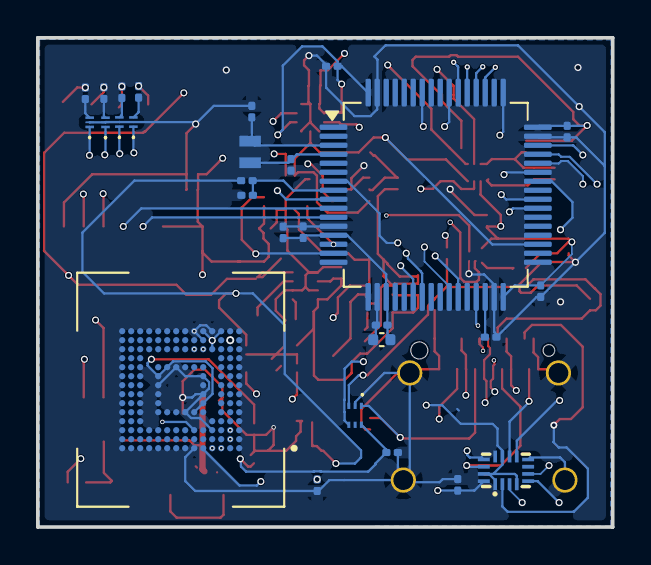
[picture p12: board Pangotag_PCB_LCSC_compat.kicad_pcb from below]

Board: 6 copper layers, 31.9 x 27.2 mm, 79 parts (28 on the bottom side), 63 nets.

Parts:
C1, C2, C3, C10, C14, C15, C18, C20, C21, C23, C26, C27, C28, C29, C31, C36, C37, C39, C40: 100n; C_0201_0603Metric
C4: 10n; C_0402_1005Metric
C7, C8, C33: 4.7u; C_0201_0603Metric
C13: 0.1u; C_0201_0603Metric
C16, C17: 8p; C_0201_0603Metric
C22, C24, C25, C35: 10u; C_0402_1005Metric
C30: 100p; C_0201_0603Metric
C38: 1u; C_0201_0603Metric
D1: XZCM2CRK53WA-1VF; LED_0603_1608Metric
D2: XZCM2CYK53WA-1VF; LED_0603_1608Metric
D3: XZCDGK53W-1VF; LED_0603_1608Metric
D4: XZCFBB53W-1VF; LED_0603_1608Metric
IC1, IC2: TLV3691IDPFR
IC3, IC4: TPS62840DLCR; SON50P150X200X100-8N-D
J1: USB_C_Receptacle; USB_C_Receptacle_Amphenol_12401610E4-2A_CircularHoles
J2: Conn_Coaxial; U.FL_Hirose_U.FL-R-SMT-1_Vertical
J5: Conn_01x02; Hirose_DF57H-2P-1.2V_1x02_P1.2mm_Socket
L1: 27n; L_0402_1005Metric
L5, L7: 2.2u; L_0805_2012Metric
Q1, Q2, Q3, Q4: PMX100UNZ
R1, R2, R19, R20: 10k; R_0201_0603Metric
R3, R4: 5.1k; R_0201_0603Metric
R5: 10; R_0402_1005Metric
R6: 900; R_0201_0603Metric
R7: 725; R_0201_0603Metric
R8, R9: 325; R_0201_0603Metric
R13: 267k; R_0201_0603Metric
R14: 909; R_0201_0603Metric
R15: 1M; R_0201_0603Metric
R16: 500k; R_0201_0603Metric
R18: 200k; R_0201_0603Metric
R21: 80M; R_0201_0603Metric
R22: 10M; R_0201_0603Metric
U1: 74AUP1G08GS_132; XSON6_SOT1202_NEX
U2: NSEC53T016T; BGA153N50P14X14_1150X1300X80
U3: T117_C19284874; TDFN-6_L2.0-W2.0-P0.65-TL-EP
U4: MAX-M10S; ublox_MAX
U5: STM32U575RGTx; LQFP-64_10x10mm_P0.5mm
U6: LTC2944IDD#PBF; DFN-8_L3.0-W3.0-P0.50-BL-EP
U7: TMUX1511RSVR; UTQFN-16_L2.6-W1.8-P0.40-BL
U8: PCA9306DQER; X2SON-8_L1.4-W1.0-P0.35-BL
U14: BMP581
U16: BMI270; BMI270_BOS
Y1: CM9V-T1A-32.768KHZ-7PF-20PPM-TA-QC; XTAL_CM9V-T1A-32.768KHZ-7PF-20PPM-TA-QC

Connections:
+3V3: C2.2, C24.1, C29.2, D1.2 (A), D2.2 (A), D3.2 (A), D4.2 (A), IC3.8 (VOS), L5.1, R5.1, R18.1, R19.1, R20.1, U2.E6 (VCC), U2.F5 (VCC), U2.J10 (VCC), U2.K9 (VCC), U5.48 (VDDUSB)
ACC_INT1: U5.14 (PA0), U16.4 (INT1)
ACC_INT2: U5.15 (PA1), U16.9 (INT2)
CC1: IC1.1 (IN+), J1.A5 (CC1), R3.1
CC2: IC2.1 (IN+), J1.B5 (CC2), R4.1
GND: C1.2, C2.1, C3.2, C4.2, C7.2, C8.2, C10.2, C13.2, C14.2, C15.2, C16.1, C17.1, C18.2, C20.1, C21.2, C22.2, C23.2, C24.2, C25.2, C26.2, C27.2, C28.2, C29.1, C30.2, C31.2, C33.2, C35.1, C36.1, C37.1, C38.1, C39.1, C40.1, IC1.2 (GND), IC2.2 (GND), IC3.1 (GND), IC3.3 (MODE), IC3.6 (STOP), IC4.1 (GND), IC4.3 (MODE), IC4.6 (STOP), J1.A1 (GND), J1.A12 (GND), J1.B1 (GND), J1.B12 (GND), J1.SH (SHIELD), J2.2 (Ext), J5.2, Q1.2 (S), Q2.2 (S), Q3.2 (S), Q4.2 (S), R3.2, R4.2, R13.2, R14.2, R16.2, R22.2, U1.3 (GND), U2.A6 (VSS), U2.C4 (VSSQ), U2.E7 (VSS), U2.G5 (VSS), U2.H10 (VSS), U2.J5 (VSS), U2.K8 (VSS), U2.N2 (VSSQ), U2.N5 (VSSQ), U2.P4 (VSSQ), U2.P6 (VSSQ), U3.2 (GND), U3.4 (ADDR), U3.7 (EP), U4.1 (GND), U4.10 (GND), U4.12 (GND), U5.12 (VSSA), U5.18 (VSS), U5.31 (VSS), U5.47 (VSS), U5.63 (VSS), U6.2 (GND), U6.3 (GND), U6.7 (GND), U6.9 (EP), U7.8 (GND), U8.1 (GND), U14.3 (GND), U14.5 (SDO/ADR), U14.8 (GND), U14.9 (GND), U16.1 (SDO), U16.6 (GNDIO), U16.7 (GND)
GPS_EXTINT: U4.5 (EXTINT), U5.11 (PC3)
I2C1_SCL: R1.1, U3.1 (SCL), U4.17 (SCL), U5.29 (PB10), U8.3 (SCL1), U14.2 (SCK/SCL), U16.13 (SCX)
I2C1_SCL_3V3: R19.2, U6.4 (SCL), U8.6 (SCL2)
I2C1_SDA: R2.1, U3.6 (SDA), U4.16 (SDA), U5.35 (PB14), U8.4 (SDA1), U14.4 (SDI/SDA), U16.14 (SDX)
I2C1_SDA_3V3: R20.2, U6.5 (SDA), U8.5 (SDA2)
LED1: Q1.1 (G), U5.27 (PB1)
LED2: Q2.1 (G), U5.26 (PB0)
LED3: Q3.1 (G), U5.23 (PA7)
LED4: Q4.1 (G), U5.22 (PA6)
NRST: U5.7 (NRST), U7.13 (D4)
unnamed: C4.1, L1.1, R5.2
unnamed: D1.1 (K), R6.2
unnamed: D2.1 (K), R7.2
unnamed: D3.1 (K), R8.2
unnamed: D4.1 (K), R9.2
unnamed: IC1.3 (IN-), IC2.3 (IN-), R21.2, R22.1
unnamed: IC1.4 (OUT), U1.1 (B)
unnamed: IC2.4 (OUT), U1.2 (A)
unnamed: IC3.7 (SW), L5.2
unnamed: IC3.5 (VSET), R13.1
unnamed: IC4.7 (SW), L7.2
unnamed: IC4.5 (VSET), R14.1
unnamed: J1.B11 (RX1+), U7.10 (S3)
unnamed: J1.B8 (SBU2), U7.14 (S4)
unnamed: J1.A2 (TX1+), U7.2 (S1)
unnamed: J1.B3 (TX2-), U7.5 (S2)
unnamed: Q1.3 (D), R6.1
unnamed: Q2.3 (D), R7.1
unnamed: Q3.3 (D), R8.1
unnamed: Q4.3 (D), R9.1
unnamed: C3.1, U2.C2 (VDDi)
unnamed: C33.1, U5.30 (VCAP)
unnamed: C14.1, C30.1, R18.2, U8.7 (VREF2), U8.8 (EN)
OSC32_IN: C17.2, U5.3 (PC14), Y1.2
OSC32_OUT: C16.2, U5.4 (PC15), Y1.1
PRS_INT: U5.9 (PC1), U14.7 (INT)
RF_IN: J2.1 (In), L1.2, U4.11 (RF_IN)
SDMMC1_CK: U2.M6 (CLK), U5.53 (PC12)
SDMMC1_CMD: U2.M5 (CMD), U5.54 (PD2)
SDMMC1_D0: U2.A3 (DAT0), U5.39 (PC8)
SDMMC1_D1: U2.A4 (DAT1), U5.40 (PC9)
SDMMC1_D2: U2.A5 (DAT2), U5.51 (PC10)
SDMMC1_D3: U2.B2 (DAT3), U5.52 (PC11)
SWCLK: U5.49 (PA14), U7.3 (D1)
SWDIO: U5.46 (PA13), U7.6 (D2)
SWO: U5.55 (PB3), U7.9 (D3)
Timepulse: U4.4 (TIMEPULSE), U5.10 (PC2)
USART1_RX: U4.2 (TXD), U5.43 (PA10)
USART1_TX: U4.3 (RXD), U5.58 (PB6)
USBC_FUNCTION: U1.4 (Y), U7.1 (SEL1), U7.4 (SEL2), U7.11 (SEL3), U7.15 (SEL4)
USB_OTG_FS_D+: J1.A6 (D+), J1.B6 (D+), U5.45 (PA12)
USB_OTG_FS_D-: J1.A7 (D-), J1.B7 (D-), U5.44 (PA11)
USB_OTG_VBUS: J1.A4 (VBUS), J1.A9 (VBUS), J1.B4 (VBUS), J1.B9 (VBUS), U5.42 (PA9)
VBAT/3: R15.2, R16.1, U5.8 (PC0)
VDD: C13.1, J5.1, R15.1, U6.8 (SENSE–)
VDD2: C7.1, C8.1, IC3.2 (VIN), IC3.4 (EN), IC4.2 (VIN), IC4.4 (EN), U6.1 (SENSE+)
VDDA: C1.1, C10.1, C15.1, C18.1, C20.2, C21.1, C22.1, C23.1, C25.1, C26.1, C27.1, C28.1, C31.1, C35.2, C36.2, C37.2, C38.2, C39.2, C40.2, IC1.6 (VCC), IC2.6 (VCC), IC4.8 (VOS), L7.1, R1.2, R2.2, R21.1, U1.6 (VCC), U2.C6 (VCCQ), U2.M4 (VCCQ), U2.N4 (VCCQ), U2.P3 (VCCQ), U2.P5 (VCCQ), U3.5 (VDD), U4.6 (V_BCKP), U4.7 (VCC_IO), U4.8 (VCC), U5.13 (VDDA), U5.19 (VDD), U5.32 (VDD), U5.64 (VDD), U7.16 (VDD), U8.2 (VREF1), U14.1 (VDDIO), U14.6 (CSB), U14.10 (VDD), U16.5 (VDDIO), U16.8 (VDD)

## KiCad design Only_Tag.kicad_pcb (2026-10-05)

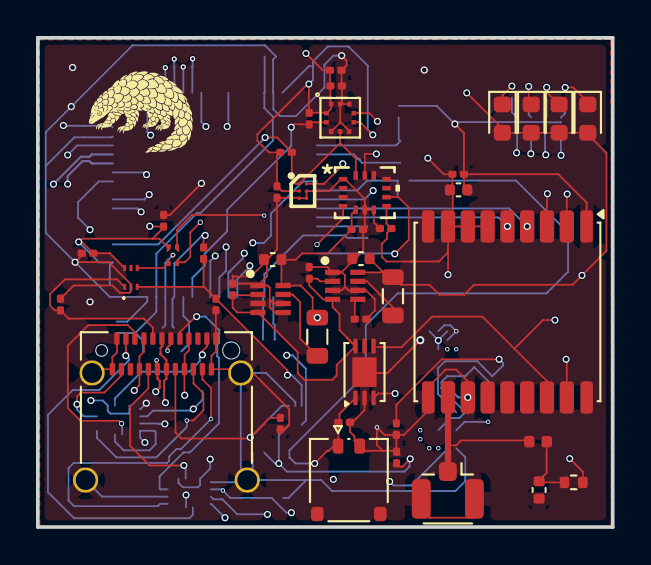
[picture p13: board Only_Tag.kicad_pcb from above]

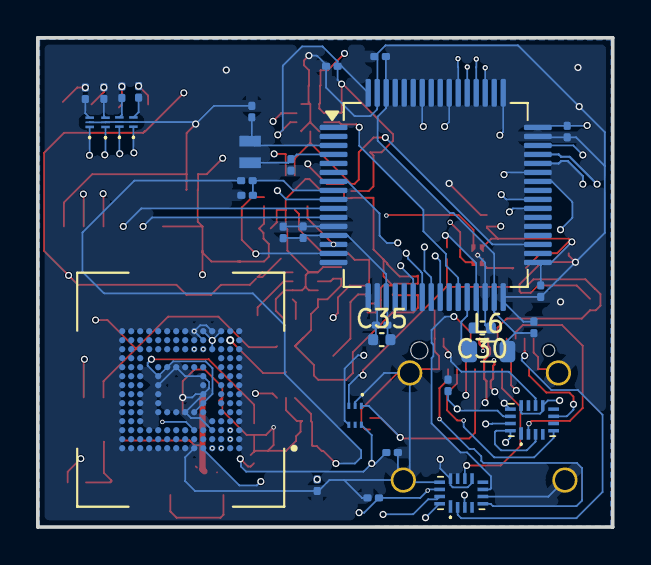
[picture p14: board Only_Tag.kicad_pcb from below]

Board: 6 copper layers, 31.9 x 27.2 mm, 77 parts (33 on the bottom side), 64 nets.

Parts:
C1, C2, C3, C10, C15, C18, C20, C21, C23, C26, C27, C28, C29, C31, C32, C36, C37, C39, C40: 100n; C_0201_0603Metric
C4: 10n; C_0402_1005Metric
C7, C8: 4.7u; C_0201_0603Metric
C13: 0.1u; C_0201_0603Metric
C16, C17: 8p; C_0201_0603Metric
C22, C24, C25, C30, C35: 10u; C_0402_1005Metric
C38: 1u; C_0201_0603Metric
C41, C42: 2.2u; C_0201_0603Metric
D1: XZCM2CRK53WA-1VF; LED_0603_1608Metric
D2: XZCM2CYK53WA-1VF; LED_0603_1608Metric
D3: XZCDGK53W-1VF; LED_0603_1608Metric
D4: XZCFBB53W-1VF; LED_0603_1608Metric
IC1, IC2: TLV3691IDPFR
IC3, IC4: TPS62840DLCR; SON50P150X200X100-8N-D
IC5, IC6: TS3A5018RSVR
J1: USB_C_Receptacle; USB_C_Receptacle_Amphenol_12401610E4-2A_CircularHoles
J2: Conn_Coaxial; U.FL_Hirose_U.FL-R-SMT-1_Vertical
J5: Conn_01x02; Hirose_DF57H-2P-1.2V_1x02_P1.2mm_Socket
L1: 27n; L_0402_1005Metric
L5, L6, L7: 2.2u; L_0805_2012Metric
Q1, Q2, Q3, Q4: PMX100UNZ
R1, R2: 10k; R_0201_0603Metric
R3, R4: 5.1k; R_0201_0603Metric
R5: 10; R_0402_1005Metric
R6: 900; R_0201_0603Metric
R7: 725; R_0201_0603Metric
R8, R9: 325; R_0201_0603Metric
R13: 267k; R_0201_0603Metric
R15: 1M; R_0201_0603Metric
R16: 500k; R_0201_0603Metric
R21: 80M; R_0201_0603Metric
R22: 10M; R_0201_0603Metric
U2: NSEC3T016-IT; BGA153N50P14X14_1150X1300X80
U3: SN74AUP1G08DPWR; DPW0005A_TEX
U4: MAX-M10S; ublox_MAX
U7: LTC2941IDCB-1#TRMPBF; DFN-6-1EP_3x2mm_P0.5mm_EP1.65x1.35mm
U8: STM32U585RITxQ; LQFP-64_10x10mm_P0.5mm
U11: AS6221T-AWLT; BGA6C40P2X3_102X150X52
U14: BMP581
U16: BMI270; BMI270_BOS
Y1: CM9V-T1A-32.768KHZ-7PF-20PPM-TA-QC; XTAL_CM9V-T1A-32.768KHZ-7PF-20PPM-TA-QC

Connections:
+3V3: C2.2, C24.1, C29.2, D1.2 (A), D2.2 (A), D3.2 (A), D4.2 (A), IC3.8 (VOS), L5.1, R5.1, U2.E6 (VCC), U2.F5 (VCC), U2.J10 (VCC), U2.K9 (VCC), U8.48 (VDDUSB)
ACC_INT1: U8.14 (PA0), U16.4 (INT1)
ACC_INT2: U8.15 (PA1), U16.9 (INT2)
CC1: IC1.1 (IN+), J1.A5 (CC1), R3.1
CC2: IC2.1 (IN+), J1.B5 (CC2), R4.1
GND: C1.2, C2.1, C3.2, C4.2, C7.2, C8.2, C10.2, C13.2, C15.2, C16.1, C17.1, C18.2, C20.1, C21.2, C22.2, C23.2, C24.2, C25.2, C26.2, C27.2, C28.2, C29.1, C30.1, C31.2, C32.2, C35.1, C36.1, C37.1, C38.1, C39.1, C40.1, C41.2, C42.2, IC1.2 (GND), IC2.2 (GND), IC3.1 (GND), IC3.3 (MODE), IC3.6 (STOP), IC4.1 (GND), IC4.3 (MODE), IC4.5 (VSET), IC4.6 (STOP), IC5.6 (GND), IC5.13 (~EN), IC6.13 (~EN), J1.A1 (GND), J1.A12 (GND), J1.B1 (GND), J1.B12 (GND), J1.SH (SHIELD), J2.2 (Ext), J5.2, Q1.2 (S), Q2.2 (S), Q3.2 (S), Q4.2 (S), R3.2, R4.2, R13.2, R16.2, R22.2, U2.A6 (VSS), U2.C4 (VSSQ), U2.E7 (VSS), U2.G5 (VSS), U2.H10 (VSS), U2.J5 (VSS), U2.K8 (VSS), U2.N2 (VSSQ), U2.N5 (VSSQ), U2.P4 (VSSQ), U2.P6 (VSSQ), U3.3 (GND), U4.1 (GND), U4.10 (GND), U4.12 (GND), U7.2 (GND), U7.7 (EP), U8.12 (VSSA), U8.18 (VSS), U8.30 (VSSSMPS), U8.32 (VSS), U8.47 (VSS), U8.63 (VSS), U11.B2 (VSS), U11.C1 (ADD0), U11.C2 (ALERT), U14.3 (GND), U14.5 (SDO/ADR), U14.8 (GND), U14.9 (GND), U16.1 (SDO), U16.6 (GNDIO), U16.7 (GND)
GPS_EXTINT: U4.5 (EXTINT), U8.11 (PC3)
I2C1_SCL: R1.1, U4.17 (SCL), U7.3 (SCL), U8.27 (PB10), U11.A2 (SCL), U14.2 (SCK/SCL), U16.13 (SCX)
I2C1_SDA: R2.1, U4.16 (SDA), U7.4 (SDA), U8.35 (PB14), U11.A1 (SDA), U14.4 (SDI/SDA), U16.14 (SDX)
LED1: Q1.1 (G), U8.25 (PB1)
LED2: Q2.1 (G), U8.24 (PB0)
LED3: Q3.1 (G), U8.23 (PA7)
LED4: Q4.1 (G), U8.22 (PA6)
NRST: IC5.9 (NC3), IC5.12 (NC4), U8.7 (NRST)
unnamed: C4.1, L1.1, R5.2
unnamed: C41.1, C42.1, L6.2, U8.31 (VDD11), U8.62 (VDD11)
unnamed: D1.1 (K), R6.2
unnamed: D2.1 (K), R7.2
unnamed: D3.1 (K), R8.2
unnamed: D4.1 (K), R9.2
unnamed: IC1.3 (IN-), IC2.3 (IN-), R21.2, R22.1
unnamed: IC1.4 (OUT), U3.1 (A)
unnamed: IC2.4 (OUT), U3.2 (B)
unnamed: IC3.7 (SW), L5.2
unnamed: IC3.5 (VSET), R13.1
unnamed: IC4.7 (SW), L7.2
unnamed: IC5.2 (COM1), J1.A2 (TX1+)
unnamed: IC5.5 (COM2), J1.B2 (TX2+)
unnamed: IC5.7 (COM3), J1.A8 (SBU1)
unnamed: IC5.10 (COM4), J1.B8 (SBU2)
unnamed: IC6.2 (COM1), J1.A3 (TX1-)
unnamed: IC6.5 (COM2), J1.B3 (TX2-)
unnamed: IC6.7 (COM3), J1.B11 (RX1+)
unnamed: IC6.10 (COM4), J1.A11 (RX2+)
unnamed: Q1.3 (D), R6.1
unnamed: Q2.3 (D), R7.1
unnamed: Q3.3 (D), R8.1
unnamed: Q4.3 (D), R9.1
unnamed: C3.1, U2.C2 (VDDi)
OSC32_IN: C17.2, U8.3 (PC14), Y1.2
OSC32_OUT: C16.2, U8.4 (PC15), Y1.1
PRS_INT: U8.9 (PC1), U14.7 (INT)
RF_IN: J2.1 (In), L1.2, U4.11 (RF_IN)
SDMMC1_CK: U2.M6 (CLK), U8.53 (PC12)
SDMMC1_CMD: U2.M5 (CMD), U8.54 (PD2)
SDMMC1_D0: U2.A3 (DAT0), U8.39 (PC8)
SDMMC1_D1: U2.A4 (DAT1), U8.40 (PC9)
SDMMC1_D2: U2.A5 (DAT2), U8.51 (PC10)
SDMMC1_D3: U2.B2 (DAT3), U8.52 (PC11)
SWCLK: IC5.3 (NC2), IC5.16 (NC1), U8.49 (PA14)
SWDIO: IC6.3 (NC2), IC6.16 (NC1), U8.46 (PA13)
SWO: IC6.9 (NC3), IC6.12 (NC4), U8.55 (PB3)
Timepulse: U4.4 (TIMEPULSE), U8.10 (PC2)
USART1_RX: U4.2 (TXD), U8.43 (PA10)
USART1_TX: U4.3 (RXD), U8.58 (PB6)
USBC_FUNCTION: IC5.15 (IN), IC6.15 (IN), U3.4 (Y)
USB_OTG_FS_D+: J1.A6 (D+), J1.B6 (D+), U8.45 (PA12)
USB_OTG_FS_D-: J1.A7 (D-), J1.B7 (D-), U8.44 (PA11)
USB_OTG_VBUS: J1.A4 (VBUS), J1.A9 (VBUS), J1.B4 (VBUS), J1.B9 (VBUS), U8.42 (PA9)
VBAT/3: R15.2, R16.1, U8.8 (PC0)
VDD: C13.1, J5.1, R15.1, U7.1 (SENSE+)
VDD2: C7.1, C8.1, IC3.2 (VIN), IC3.4 (EN), IC4.2 (VIN), IC4.4 (EN), U7.6 (SENSE–)
VDDA: C1.1, C10.1, C15.1, C18.1, C20.2, C21.1, C22.1, C23.1, C25.1, C26.1, C27.1, C28.1, C30.2, C31.1, C32.1, C35.2, C36.2, C37.2, C38.2, C39.2, C40.2, IC1.6 (VCC), IC2.6 (VCC), IC4.8 (VOS), IC5.14 (V+), IC6.14 (V+), L7.1, R1.2, R2.2, R21.1, U2.C6 (VCCQ), U2.M4 (VCCQ), U2.N4 (VCCQ), U2.P3 (VCCQ), U2.P5 (VCCQ), U3.5 (VCC), U4.6 (V_BCKP), U4.7 (VCC_IO), U4.8 (VCC), U8.13 (VDDA), U8.19 (VDD), U8.29 (VDDSMPS), U8.33 (VDD), U8.64 (VDD), U11.B1 (VDD), U14.1 (VDDIO), U14.6 (CSB), U14.10 (VDD), U16.5 (VDDIO), U16.8 (VDD)
VLXSMPS: L6.1, U8.28 (VLXSMPS)

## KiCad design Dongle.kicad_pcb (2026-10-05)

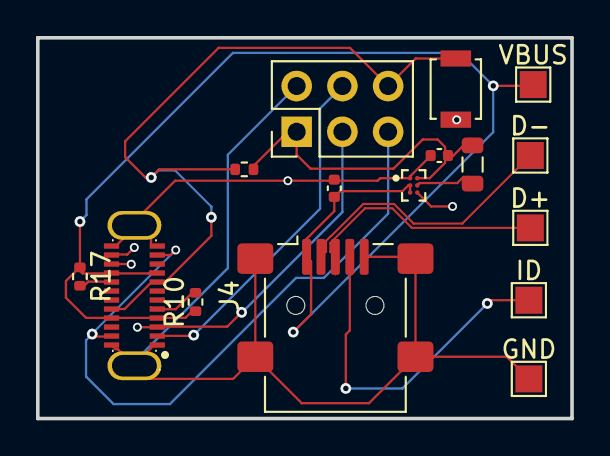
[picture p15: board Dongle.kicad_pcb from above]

Board: 4 copper layers, 29.7 x 21.2 mm, 16 parts (0 on the bottom side), 13 nets.

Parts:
C11: 4.7u; C_0402_1005Metric
C19: 10u; C_0402_1005Metric
CN2: POGOPIN_2X04_P2.54_M; PinHeader_2x03_P2.54mm_Vertical
D+: MountingHole_Pad; TestPoint_Pad_1.5x1.5mm
D-: MountingHole_Pad; TestPoint_Pad_1.5x1.5mm
GND: MountingHole_Pad; TestPoint_Pad_1.5x1.5mm
ID: MountingHole_Pad; TestPoint_Pad_1.5x1.5mm
J3: USB_B_Mini; USB_Mini-B_Lumberg_2486_01_Horizontal
J4: UP32-C-F-G-FL-3-P24-TR; USB-TH-TYPE-C_00702-UCAM002-X
L4: 2.2u; L_0805_2012Metric
R10, R17: 56k; R_0402_1005Metric
R12: 10k; R_0402_1005Metric
SW1: SW_Push; SW_SPST_B3U-1000P
U18: TPS62840YBGR; BGA6N40P3X2_146X96X50N
VBUS: MountingHole_Pad; TestPoint_Pad_1.5x1.5mm

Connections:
+1V8_2: C19.1, CN2.1, L4.2, R12.1, U18.A2 (VOS)
GND2: C11.2, C19.2, CN2.2, GND.1 (1_1), J3.5 (GND), J3.SH (Shield), J4.14, J4.A1 (GND_1), J4.A12 (GND_2), J4.B1 (GND_3), J4.B12 (GND_4), SW1.2, U18.A1 (GND), U18.C2 (VSET)
NRST_OUT: CN2.6, J4.A8 (SBU1), J4.B8 (SBU2), R12.2, SW1.1
unnamed: ID.1 (1_1), J3.4 (ID)
unnamed: J4.A5 (CC1), R10.2
unnamed: J4.B5 (CC2), R17.2
unnamed: L4.1, U18.B2 (SW)
ST_D+: D+.1 (1_1), J3.3 (D+)
ST_D-: D-.1 (1_1), J3.2 (D-)
SWCLK_OUT: CN2.4, J4.A2 (SSTXP1), J4.B2 (SSTXP2)
SWDIO_OUT: CN2.3, J4.A3 (SSTXN1), J4.B3 (SSTXN2)
SWO_OUT: CN2.5, J4.A11 (SSRXP2), J4.B11 (SSRXP1)
VBUS_DONGLE: C11.1, J3.1 (VBUS), J4.A4 (VBUS_1), J4.A9 (VBUS_2), J4.B4 (VBUS_3), J4.B9 (VBUS_4), R10.1, R17.1, U18.B1 (VIN), U18.C1 (EN), VBUS.1 (1_1)

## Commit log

2026-07-09 preliminary pcb updates
    [Pangotag_PCB.kicad_pcb, Pangotag_PCB.kicad_sch]
2026-07-14 hierarchical sheets added
    [Communication.kicad_sch, LEDs.kicad_sch, Power.kicad_sch]
2026-07-14 replaced MCU
    [Communication.kicad_sch]
2026-07-21 layout done
    [Communication.kicad_sch, LEDs.kicad_sch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]
2026-10-05 Add V2: STM32U575 LQFP-64 tag board and ST-Link dongle
    The tag moves from the 23 × 18 mm STM32U585 WLCSP-90 layout to a
    31.94 × 27.18 mm, 6-layer board (Pangotag_PCB_LCSC_compat4.kicad_pcb) with
    an LQFP-64 STM32U575, a MAX-M10S GNSS module, a 32 GB eMMC and parts that
    JLCPCB stocks. Adds the USB-C debug dongle, the intermediate revisions, the
    JLCPCB production files, the project footprint and symbol libraries, BOMs
    and renders, plus a README.
    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
    [BOM-Dongle.csv, BOM-Only_Tag.csv, BOM-Only_Tag2.csv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]
